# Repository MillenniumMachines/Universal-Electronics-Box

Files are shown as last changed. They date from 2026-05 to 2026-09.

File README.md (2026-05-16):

# Universal Electronics Box

Modular DIN-rail electronics enclosure for Millennium CNC builds—designed to pair with [Milo V2 / Miley V2](https://github.com/MillenniumMachines/Milo-V2.0).

**Repository:** [github.com/MillenniumMachines/Universal-Electronics-Box](https://github.com/MillenniumMachines/Universal-Electronics-Box)

This repository contains **STLs**, **panel DXFs**, **master CAD**, the **bill of materials** spreadsheet, **print list**, and the **wiring reference PDF**. Human-readable BOM, print settings, and part tables live on the [UEB section of the Millennium Machines documentation site](https://millenniummachines.github.io/docs/ueb/); see also the [main documentation hub](https://millenniummachines.github.io/docs/) for other Millennium projects.

## Documentation

| Topic | Location |
| --- | --- |
| All Millennium Machines guides | [Documentation hub](https://millenniummachines.github.io/docs/) |
| Overview, safety, repo layout | [UEB docs — Overview](https://millenniummachines.github.io/docs/ueb/) |
| Bill of materials and contactor options | [Sourcing guide](https://millenniummachines.github.io/docs/ueb/bom/sourcing_guide/) |
| Print profiles and printed parts | [Printing guide](https://millenniummachines.github.io/docs/ueb/printing/print_guide/) |
| Mains, E-stop, PSU, and signal wiring | [Millennium Universal CNC wiring .pdf](Millennium%20Universal%20CNC%20wiring%20.pdf) |
| Milo mechanical build, RRF, pre-flight | [MiloV2-Manual.pdf](https://github.com/MillenniumMachines/Milo-V2.0/blob/main/Manual/MiloV2-Manual.pdf) |

Source spreadsheets in this repo (also reflected on the docs site):

- `Electronics Cabinet BOM.xlsx`
- `Milennium Universal Electronics box Print List.xlsx`

## Repository layout

```
CAD/          Master assembly STEP
DXFs/         Top/bottom and side panel outlines
STLs/
  Panels/     Covers, clips, handles, keystone blanks
  Mounts/     DIN-rail mounts (Scylla, LRS-350 PSU)
  Cable channels/   Lids and trays for wire routing
              TPU-Foot-x4-A.stl (optional feet)
```

## Printing quick reference

Use **0.2 mm** layers and a **0.4 mm** nozzle unless you are experimenting. Profile codes in filenames match the print list:

| Code | Use |
| --- | --- |
| **S** | Structural — 45% infill, 6 walls |
| **SS** | Semi-structural — 25% infill, 4 walls |
| **A** | Aesthetic — 20% infill, 3 walls |

- **`[a]`** prefix — accent filament
- **`x#`** suffix — quantity required (e.g. `x4` → four copies)
- **`Voron-Inserts`** in the filename — print the variant that matches your heat-set inserts (Voron vs CNC-Kitchen)

See the [printing guide](https://millenniummachines.github.io/docs/ueb/printing/print_guide/) for the full part list.

## Wiring

The wiring PDF is titled **V2 / V1.6 wiring reference**. It covers mains inlet, breaker, contactor, 24 V distribution, E-stop, and machine interconnect—follow it together with your local electrical code.

> **Warning:** This enclosure operates at **mains voltage**. Use a suitable E-stop, correct wire gauges for your region, and qualified help if you are unsure. Do not energize the cabinet until wiring has been checked.

## Related projects

- [Milo-V2.0](https://github.com/MillenniumMachines/Milo-V2.0) — mechanical mill (electronics not included in that repo)
- [Millennium Machines documentation](https://millenniummachines.github.io/docs/) — published guides (UEB, Milo, and other projects)
- [millenniummachines.github.io](https://github.com/MillenniumMachines/millenniummachines.github.io) — documentation site source

## License

See repository license file when published. Until then, treat CAD and STLs as part of the Millennium Machines open hardware ecosystem and follow project guidance on Discord for use and redistribution.

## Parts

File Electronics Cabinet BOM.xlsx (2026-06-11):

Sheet: Electronics
Category | Component | Standard | QTY | Note | Note 2 | Recommended | Alternative
Filament | Primary Color ABS/ASA |  | 2
Filament | Primary Color TPU |  | 1 | (OPTIONAL for the case feet) | Amazon (https://www.amazon.co.uk/Filament-1-75mm-Eryone-Printing-Printer/dp/B07XNYTPN9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)
Printed parts | Printed parts |  | 1
Fasteners | M3x10mm SHCS | ISO 4762 / DIN 912 | 40 | (extra fatseners are included in this list) | ACCU (https://www.accu.co.uk/cap-head-screws/3819-SSCF-M3-10-A2)
Fasteners | M3x30mm SHCS | ISO 4762 / DIN 912 | 6 |  | ACCU (https://www.accu.co.uk/metric-cap-head-screws/2805-SSC-M3-30-A2)
Fasteners | M4x6mm BHCS | ISO 7380-0 | 4 |  | ACCU (https://www.accu.co.uk/socket-button-screws/8127-SSB-M4-6-A2)
Fasteners | M5x10mm BHCS | ISO 7380-1 | 28 |  | ACCU (https://www.accu.co.uk/socket-button-screws/8147-SSB-M5-10-A2)
Fasteners | M5x12mm BHCS | ISO 7380-1 | 10 |  | ACCU (https://www.accu.co.uk/socket-button-screws/8148-SSB-M5-12-A2)
Fasteners | M3 heated inserts |  | 14 | (Choose between voron style or cnc kitchen style inserts) | CNC KITCHEN (https://cnckitchen.store/products/heat-set-insert-m3-x-3-short-version-100-pieces) | Aliexpress (https://s.click.aliexpress.com/e/_ol2Yb5O)
Fasteners | M5 roll in T nut |  | 2 |  | Aliexpress (https://www.aliexpress.com/item/1005004082080953.html)
Fasteners | M3 roll in T nut |  | 20 |  | Aliexpress (https://www.aliexpress.com/item/1005004082080953.html)
Fasteners | M5 serrated washer |  | 2 | (This is for grounding the Frame of the control box and whatever Machine its attached to) | Amazon (https://www.amazon.co.uk/sourcing-map-Mechanical-Equipment-Fasteners/dp/B0D9VTPJ9F?s=diy)
Frame | 2020 V-slot extrusion 140mm |  | 4 | (Tap both ends of all extrusions) | Ooznest (https://ooznest.co.uk/product/v-slot-linear-rail-20x20mm-cut-to-size/)
Frame | 2020 V-slot extrusion 430mm |  | 4 |  | Ooznest (https://ooznest.co.uk/product/v-slot-linear-rail-20x20mm-cut-to-size/)
Frame | 2020 V-slot extrusion 410mm |  | 4 |  | Ooznest (https://ooznest.co.uk/product/v-slot-linear-rail-20x20mm-cut-to-size/)
Cables | 18AWG (min) Mains wiring (neutral, line, ground) |  |  | NOTE : WIRING LENGTHS WILL CHANGE DEPENDING ON YOUR NEEDS consult your local guidelines for regulation wiring sizes
Cables | 18AWG 4 Core for spindle Power
Cables | 20AWG wire for DC power distribution
Cables | 24AWG wire for signal cables
Cables | Nylon Cable Ties (less than 5mm wide) |  | 100 |  | Amazon (https://amzn.to/3NmmzLt)
Cables | Fork Spade Terminal |  |  |  | Amazon (https://amzn.to/37Ziyxk)
Cables | Ferrule CableTerminations |  |  | (size and use where appropriate) | Amazon (https://amzn.to/3wu2NYK)
Cables | JST Connector 3 Pin |  |  |  | Amazon (https://amzn.to/3G0HRvs)
Cables | Cable Gromets for ID 30mm |  | 3 |  | Amazon (https://www.amazon.co.uk/dp/B0CLXLZ8WJ?ref=ppx_yo2ov_dt_b_fed_asin_title&th=1)
Hardware | 35mm DIN Rail 410mm |  | 2 |  | RS components (https://uk.rs-online.com/web/p/din-rails/8990917)
Panels | 186x450mm 3mm ACM/Acrylic/Polycarbonate |  | 2
Panels | 430x450mm 3mm ACM/Acrylic/Polycarbonate |  | 2
Electronics | Fan | 24V 120mm | 1 |  | amazon (https://www.amazon.co.uk/dp/B087FG4QPF?ref_=ppx_hzsearch_conn_dt_b_fed_asin_title_1&th=1)
Electronics | Estop | 2 NC | 1 |  | RS components (https://uk.rs-online.com/web/p/emergency-stop-push-buttons/1682546?matchtype=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)
Electronics | Meanwell LRS-350 | 24-60V (recommended 48V) | 1 |  | Digikey (https://www.digikey.co.uk/en/products/detail/mean-well-usa-inc/LRS-350-24/7705034)
Electronics | Meanwell HDR-30 | 24V | 1 |  | amazon (https://www.amazon.co.uk/dp/B06XWVHW8V?ref_=ppx_hzsearch_conn_dt_b_fed_asin_title_1)
Electronics | KCD4 rocker switches | 220V or 110V rated switches | 1 | only 1 is required should you want, to add more for auxiliaries go ahead | amazon (https://www.amazon.co.uk/dp/B0B7RDZKQL?ref_=ppx_hzsearch_conn_dt_b_fed_asin_title_1)
Electronics | BTT Scylla |  | 1 |  | Scylla (https://www.desktopmachineshop.com/shop/btt-scylla-v1-180?page=3)
Electronics | USB/HDMI/RJ45 keystone jacks |  | 0 to 4 | Should you wish to install a Raspberry pi there are 4 available spots for keystone jacks these are optional. | HDMI (https://www.amazon.co.uk/dp/B0CN2BW2H1?ref_=ppx_hzsearch_conn_dt_b_fed_asin_title_1&th=1) | USB (https://www.amazon.co.uk/dp/B07Z9446ZR?ref_=ppx_hzsearch_conn_dt_b_fed_asin_title_3&th=1) | RJ45 (http://amazon.co.uk/dp/B01GFWSSYQ?ref_=ppx_hzsearch_conn_dt_b_fed_asin_title_2)
Electronics | Raspberry pi 4/5 8GB |  | 0 or 1 | Optional you can use your phone/PC/tablet instead (you will need to provide your own DIN mount for the pi) | amazon (https://www.amazon.co.uk/Raspberry-Pi-SC1112-5-8GB/dp/B0CK2FCG1K)
Electronics | DIN AC terminal Hot |  | 3 | Colors may be different depending on your region, please refer to your countries electrical code | RS components (https://uk.rs-online.com/web/p/din-rail-terminal-blocks/0815694)
Electronics | DIN AC terminal Neutral |  | 3 |  | RS components (https://uk.rs-online.com/web/p/din-rail-terminal-blocks/0501819?gb=s)
Electronics | DIN AC terminal Ground |  | 3 |  | RS components (https://uk.rs-online.com/web/p/din-rail-terminal-blocks/8725621)
Electronics | Power inlet | IEC20 | 1 | You can buy combined inlet EMI filters in 110V countries eliminating the need for both | amazon (https://www.amazon.co.uk/dp/B0C4F9RYS8?ref_=ppx_hzsearch_conn_dt_b_fed_asin_title_1)
220V 2.2KW Spindle
Electronics | DIN contactor | 24V DC coil voltage, 3 channel, 220V AC @ 16A | 1 |  | TME (https://www.tme.eu/gb/details/gmd-16m-24vdc-1b/contactors-main-modules/ls-electric/gmd-16m-24vdc-1b/)
Electronics | Mini circuit breaker | 13A 220V 2 Pole | 1 |  | amazon (https://www.amazon.co.uk/dp/B0018LB3UQ?ref_=ppx_hzsearch_conn_dt_b_fed_asin_title_2)
Electronics | AC EMI filter | 13A 220V | 1 | You may be able to get away if you want to save some money with no EMI filter especially in 220V countries. If you experience any issues due to EMI add one later | amazon (https://www.amazon.co.uk/sourcingmap®-CW4L2-10A-T-Noise-Suppressor-Filter/dp/B016EISSGE?s=industrial)
Electronics | Power Cable | IEC C19 to IEC 60309 | 1 |  | amazon (https://www.amazon.co.uk/dp/B07MPP8X9M?ref_=ppx_hzsearch_conn_dt_b_fed_asin_title_1)
Electronics | VFD | 220V 2.2KW | 1
Electronics | Spindle | 2 or 4 pole 400Hz 220V 2.2KW | 1
110V 2.2KW spindle |  |  |  | WARNING Most domestic power systems in 110V countries like the US can only "just" provide enough amperage for a 2.2Kw spindle we do not recommend using one without a dedicated circuit
Electronics | DIN contactor | 24V DC coil voltage, 3 channel, 110V AC @ 20A | 1 | Contactors rated for 220V will also work for 110V but not the other way around | automation direct (https://www.automationdirect.com/adc/shopping/catalog/motor_controls/iec_magnetic_contactors/iec_contactors/hmc-22b30-11-ds)
Electronics | DIN Mini circuit breaker | 20A 110V 2 pole | 1 |  | amazon (https://amzn.to/3FzbfNO)
Electronics | AC EMI filter | 20A 110V | 1 | You may be able to get away if you want to save some money with no EMI filter. If you experience any issues due to EMI add one later | amazon (https://amzn.to/4dK8yW9)
Electronics | Power Cable | IEC C19 to Nema 5-20P | 1 |  | amazon (https://amzn.to/43Qu2MN)
Electronics | VFD | 110V 2.2KW | 1
Electronics | Spindle | 2 or 4 pole 400Hz 110V 2.2KW | 1
220V 1.5KW spindle
Electronics | DIN contactor | 24V DC coil voltage, 3 channel, 220V AC @ 16A | 1 |  | TME (https://www.tme.eu/gb/details/gmd-16m-24vdc-1b/contactors-main-modules/ls-electric/gmd-16m-24vdc-1b/)
Electronics | Mini circuit breaker | 13A 220V 2 pole | 1 |  | amazon (https://www.amazon.co.uk/dp/B0018LB3UQ?ref_=ppx_hzsearch_conn_dt_b_fed_asin_title_2)
Electronics | AC EMI filter | 13A 220V | 1 | You may be able to get away if you want to save some money with no EMI filter especially in 220V countries. If you experience any issues due to EMI add one later | amazon (https://www.amazon.co.uk/sourcingmap®-CW4L2-10A-T-Noise-Suppressor-Filter/dp/B016EISSGE?s=industrial)
Electronics | Power Cable | IEC C19 to IEC 60309 | 1 |  | amazon (https://www.amazon.co.uk/dp/B07MPP8X9M?ref_=ppx_hzsearch_conn_dt_b_fed_asin_title_1)
Electronics | VFD | 220V 1.5KW | 1 |  | DMS (https://www.desktopmachineshop.com/shop/ldo-inverter-vfd-1-5kw-220v-shinlin-38)
Electronics | Spindle | 2 or 4 pole 400Hz 220V 1.5KW | 1 |  | DMS (https://www.desktopmachineshop.com/shop/ldo-spindle-motor-1-5kw-220v-37)
110V 1.5KW spindle
Electronics | DIN contactor | 24V DC coil voltage, 3 channel, 110V AC @ 16A | 1 | Contactors rated for 220V will also work for 110V but not the other way around | automation direct (https://www.automationdirect.com/adc/shopping/catalog/motor_controls/iec_magnetic_contactors/iec_contactors/hmc-18b30-11-ds)
Electronics | Mini circuit breaker | 15A 110V 2 pole | 1 |  | amazon (https://amzn.to/4mKpShW)
Electronics | AC EMI filter | 15A 110V | 1 | You may be able to get away if you want to save some money with no EMI filter. If you experience any issues due to EMI add one later | amazon (https://amzn.to/4dK8yW9)
Electronics | Power Cable | IEC C19 to Nema 5-15P | 1 |  | amazon (https://amzn.to/3Sx5fIl)
Electronics | VFD | 110V 1.5KW | 1 |  | West3D (https://west3d.com/products/inverter-for-cnc-machines-milo-by-millennium-machines?variant=45225259696340)
Electronics | Spindle | 2 or 4 pole 400Hz 110V 1.5KW | 1 |  | West3D (https://west3d.com/products/inverter-for-cnc-machines-milo-by-millennium-machines?variant=45225259696340)

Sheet: Contactor Candidates
Manufacturer | Model | Rated Current | Rated Voltage | Poles | Auxilary Contacts | DBL Checked for 24v DC Control | Source 1 | Price | Source 2 | Price2 | Notes
Baomain | BMHC7-16 | 16 | 400 | 3 | 1NC | yes | https://baomain.com/products/baomain-dc-ac-modular-contactor-hum-free-16a-4pole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 | $15.39
Schneider Electric | LC1D18BD | 18 | 440 | 3 | 1NC+1NO | yes | https://www.amazon.com/dp/B0751H9SVM | $64.00 | https://www.aliexpress.us/item/3256807845054295.html | $33.19
Siemens | 3RT20161BB41 | 20 | 220* | 3 | 1NO | yes | https://www.amazon.com/Siemens-3RT20161BB41-Contactor-3-Pole-TERMINAL/dp/B003U6615Y/ | $38.60 | https://www.aliexpress.us/item/3256803379863717.html | $44.50 | Higher voltage rating, but amps derate at higher voltages. 20A for both 110 and 220V
Schneider Electric | DPE18BL | 40 | 220 | 3 | 1NO | yes | https://www.amazon.com/Schneider-Electric-DPE18BL-Contactor-Terminals/dp/B09B2SP56H/ | $39.98
Hofwge | HCH8s-63 | 25 | 220 | 4 |  | AC & DC | https://www.aliexpress.us/item/3256804432680878.html | $21.50
CHNT | NC1-1801Z | 18 | 380 | 3 | 1NC | yes | https://www.aliexpress.us/item/3256804690998153.html | $32.00 | https://www.aliexpress.us/item/2255800339794785.html | $18.83 | Source 2 Sale: $16.95
CHNT | NC1-1810Z | 18 | 380 | 3 | 1NO | yes |  |  | https://www.aliexpress.us/item/2255800339794785.html | $18.83 | Source 2 Sale: $16.95
CHNT | NC1-2501Z | 25 | 380 | 3 | 1NC | yes | https://www.aliexpress.us/item/3256804690998153.html | $40.00 | https://www.aliexpress.us/item/2255800339809617.html | $24.67 | Source 2 Sale: $22.20
CHNT | NC1-2510Z | 25 | 380 | 3 | 1NO | yes | https://www.aliexpress.us/item/3256804690998153.html | $40.00 | https://www.aliexpress.us/item/2255800339809617.html | $24.67 | Source 2 Sale: $22.21
Altech Corporation | GMD-16M-10-DC24V | 20 | 440 | 3 | 1NC | yes | https://www.tme.eu/gb/details/gmd-16m-24vdc-1b/contactors-main-modules/ls-electric/gmd-16m-24vdc-1b/ | $18.75 | https://us.misumi-ec.com/vona2/detail/110400268240/?HissuCode=GMD-16M-DC24V | $36.32 | Source 1: High shipping cost to US; Source 2 Sale: $14.49

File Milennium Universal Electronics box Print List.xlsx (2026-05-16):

Print Setting Name | Wall Count | Top/Bottom layers | Nozzle Size | Layer Height | Infill % | Infill Type
A (aesthetic) | 3 | 5 | 0.4mm | 0.2mm | 20 | Gyroid/Cubic
SS (semi structural) | 4 | 5 | 0.4mm | 0.2mm | 25 | Gyroid/Cubic
S (structural) | 6 | 6 | 0.4mm | 0.2mm | 45 | Gyroid/Cubic
Part Category | Part Name | Print Setting | Material | Quantity | Accent color Y/N | Note
Panels | [a]-Keystone-Blank-Insert-x4-A | A | ABS | 4 | Y | This is a VORON DESIGN part Go check them out (https://vorondesign.com/)
Panels | Extrusion-Handle-x2-A | A | ABS | 2 | N
Panels | Front-Estop-cover-34mm-x1-SS | SS | ABS | 1 | N
Panels | Front-Inlet-Cover-x1-A | A | ABS | 1 | N
Panels | Front-Mid-Cover-x1-A | A | ABS | 1 | N
Panels | Panel-Clip-F-x2-A | A | ABS | 2 | N
Panels | Rear-Inlet-Cover-Voron-Inserts-x1-A | A | ABS | 1 | N
Panels | Rear-Inlet-Cover-x1-A | A | ABS | 1 | N
Panels | Rear-lower-cover-x1-A | A | ABS | 1 | N
Panels | Rear-Mid-Cover-x1-A | A | ABS | 1 | N
Mounts | Din-Rail-Enclosure-Mount-x4-A | A | ABS | 4 | N
Mounts | LRS-350-DIN-Mount-x1-or-2-SS | SS | ABS | 1 or 2 | N | If your VFD isn't too big i'd recommend printing 2
Mounts | Scylla-Din-Adapter-Left-x1-SS | SS | ABS | 1 | N
Mounts | Scylla-Din-Adapter-Left-Voron-Inserts-x1-SS | SS | ABS | 1 | N
Mounts | Scylla-Din-Adapter-Right-x1-SS | SS | ABS | 1 | N
Mounts | Scylla-Din-Adapter-Right-Voron-Inserts-x1-SS | SS | ABS | 1 | N
Mounts | Scylla-Din-Mount-x2-SS | SS | ABS | 2 | N
Cable Channels | 145mm-Lid-x4-A | A | ABS | 4 | N | All of the cable ducts were made using THIS tool then modified further check it out (https://www.printables.com/model/516164-cable-raceway)
Cable Channels | 145mm-Tray-x4-A | A | ABS | 4 | N
Cable Channels | 165mm-Lid-x6-A | A | ABS | 6 | N
Cable Channels | 165mm-Tray-x6-A | A | ABS | 6 | N
Cable Channels | Corner-Lid-x4-A | A | ABS | 4 | N
Cable Channels | Corner-Tray-x4-A | A | ABS | 4 | N
Cable Channels | T-Junction-Lid-x2-A | A | ABS | 2 | N
Cable Channels | T-Junction-Tray-x2-A | A | ABS | 2 | N
Feet | TPU-Foot-x4-A | A | TPU | 4 | N

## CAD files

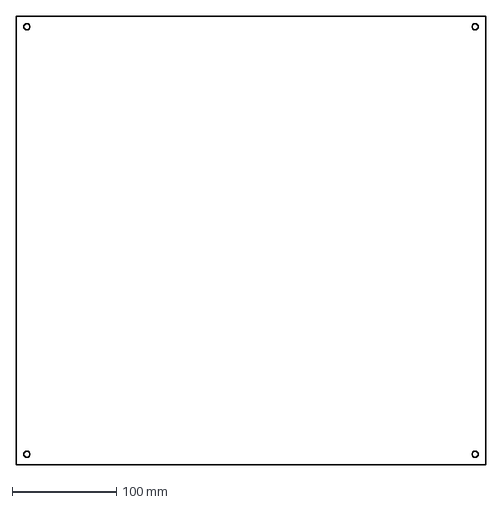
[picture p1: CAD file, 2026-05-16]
DXFs/Side-Panels-x2.dxf
450.0 x 430.0 mm

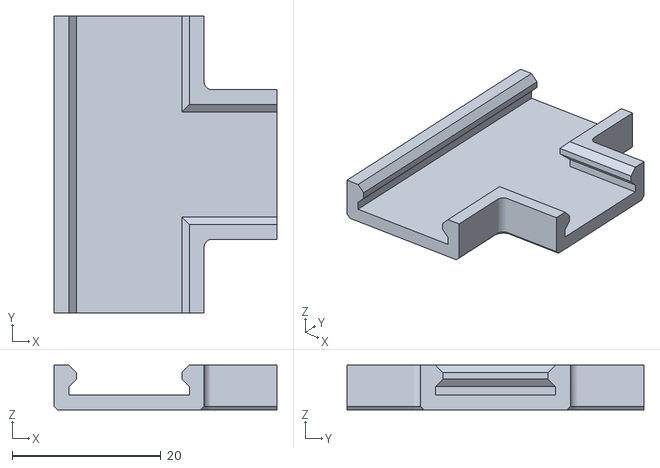
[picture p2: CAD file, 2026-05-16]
STLs/Cable channels/T-Junction-Lid-x2-A.stl
30.0 x 40.0 x 6.06

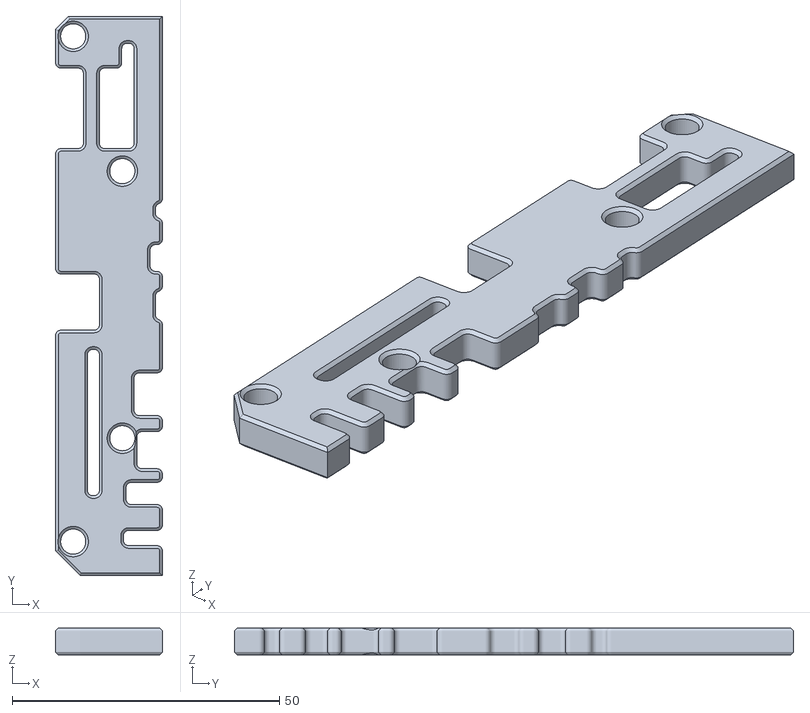
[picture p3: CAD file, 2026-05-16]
STLs/Mounts/Scylla-Din-Adapter-Left-Voron-Inserts-x1-SS.stl
20.0 x 104.6 x 5.00

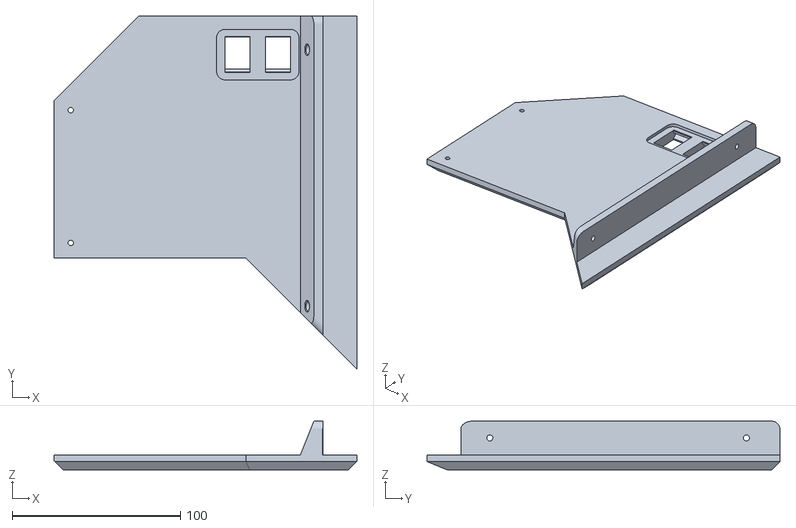
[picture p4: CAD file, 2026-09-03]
STLs/Panels/Front-Mid-Cover-x1-A.stl
180.0 x 209.9 x 29.0

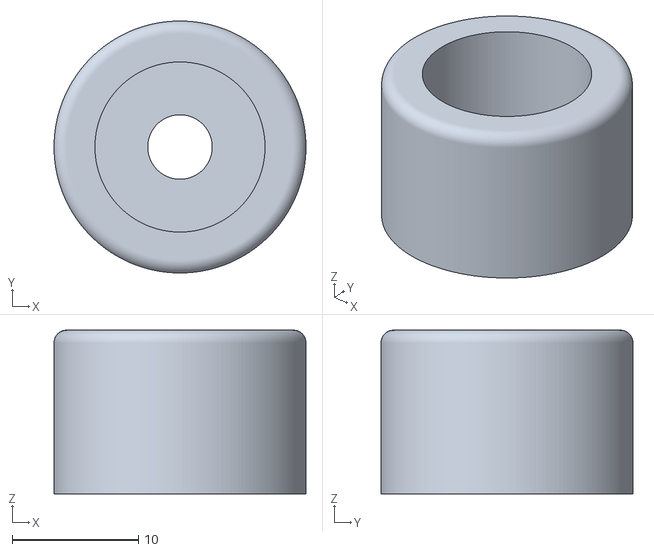
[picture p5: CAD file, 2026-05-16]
STLs/TPU-Foot-x4-A.stl
20.0 x 20.0 x 13.0

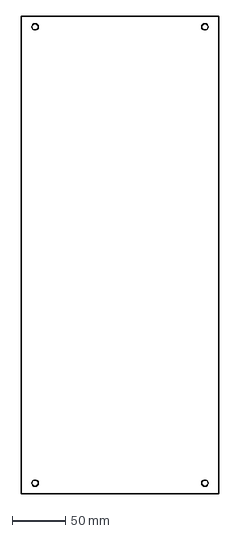
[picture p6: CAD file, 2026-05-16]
DXFs/Top-Bottom-Panel-x2.dxf
186.0 x 450.0 mm

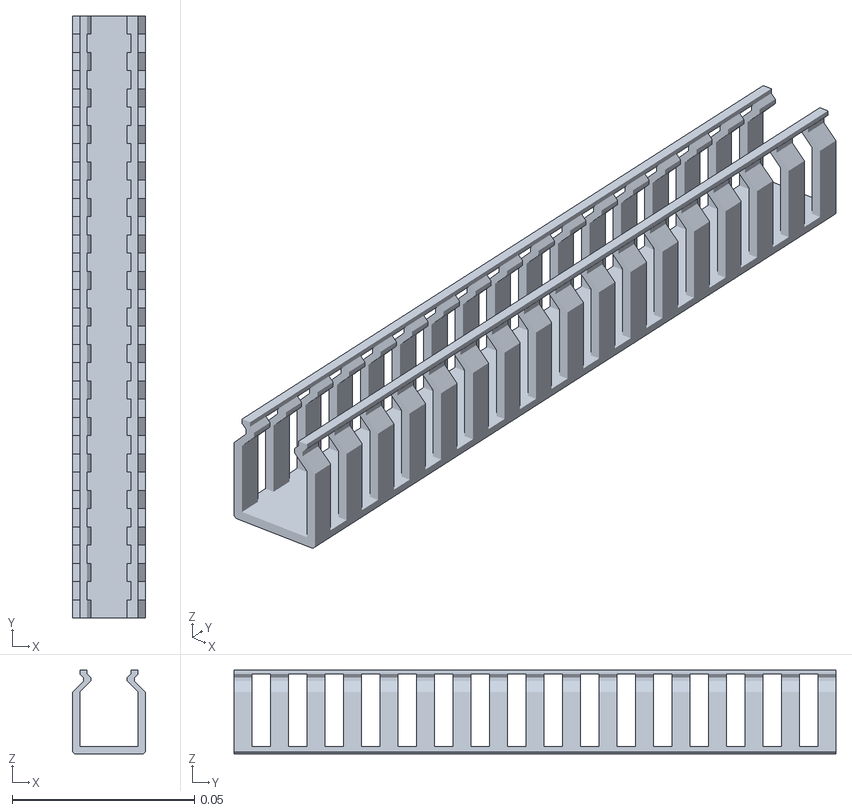
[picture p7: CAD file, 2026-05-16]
STLs/Cable channels/165mm-Tray-x6-A.stl
0.02 x 0.165 x 0.0229

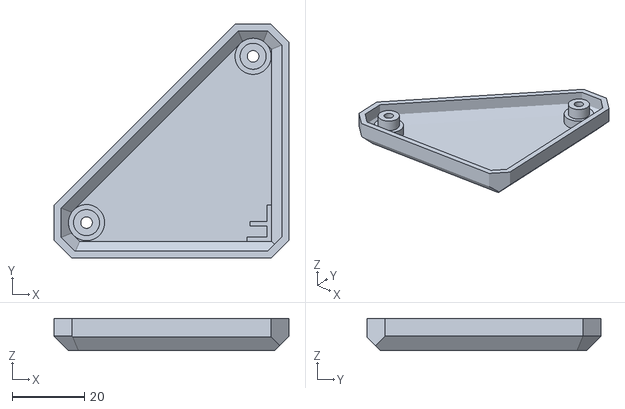
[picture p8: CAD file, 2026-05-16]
STLs/Panels/Panel-Clip-F-x2-A.stl
65.0 x 64.9 x 8.96

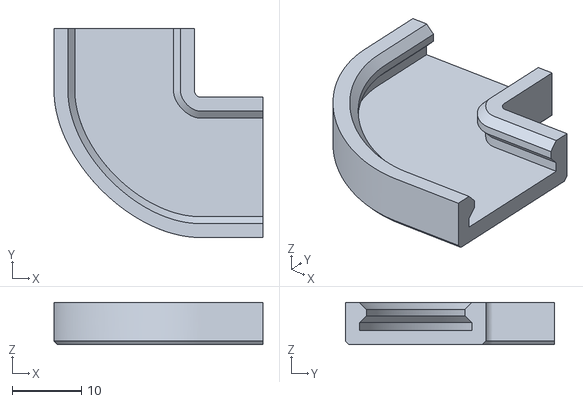
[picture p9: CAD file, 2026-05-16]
STLs/Cable channels/Corner-Lid-x4-A.stl
30.1 x 30.1 x 6.06

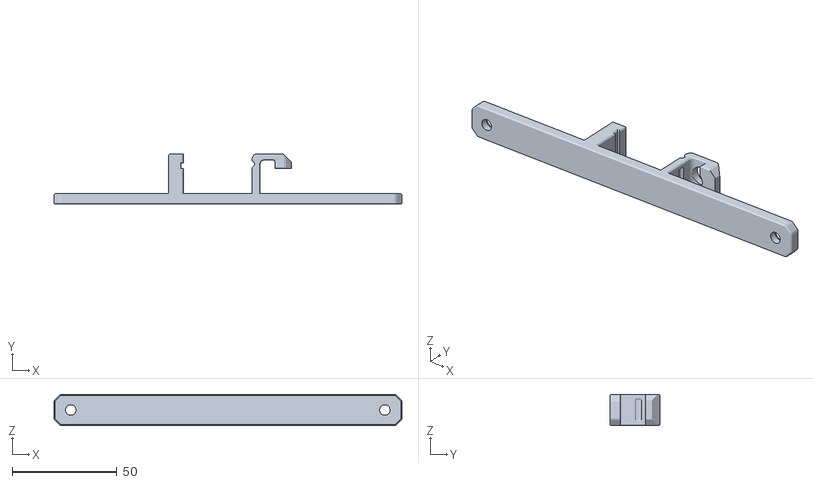
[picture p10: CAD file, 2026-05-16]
STLs/Mounts/LRS-350-DIN-Mount-x1-or-2-SS.stl
166.2 x 24.0 x 15.0

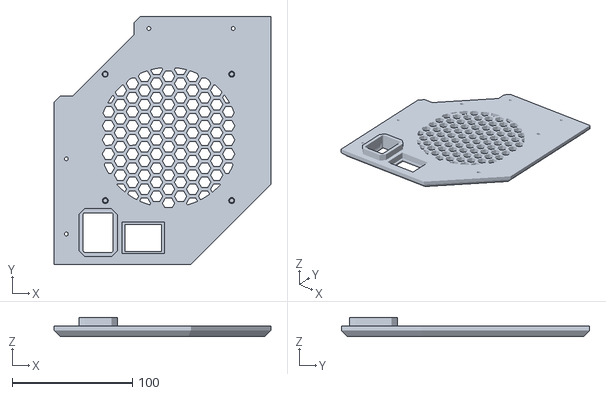
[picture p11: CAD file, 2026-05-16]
STLs/Panels/Rear-Inlet-Cover-x1-A.stl
180.0 x 206.0 x 16.0

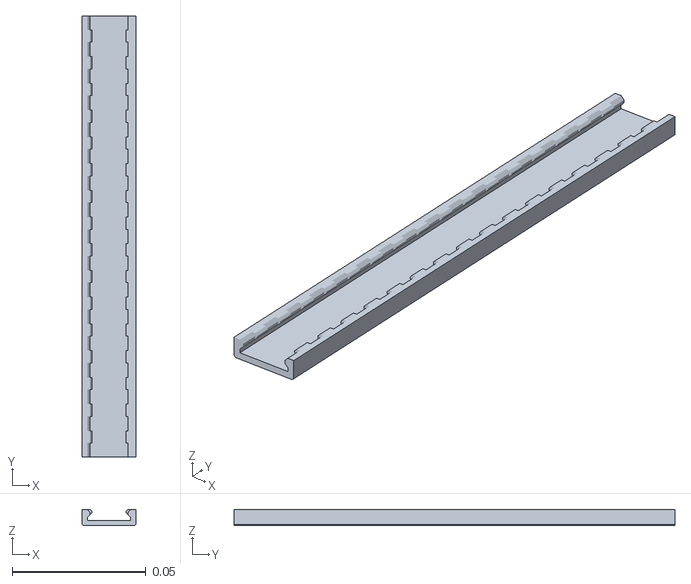
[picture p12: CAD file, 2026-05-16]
STLs/Cable channels/165mm-Lid-x6-A.stl
0.0202 x 0.165 x 0.00606

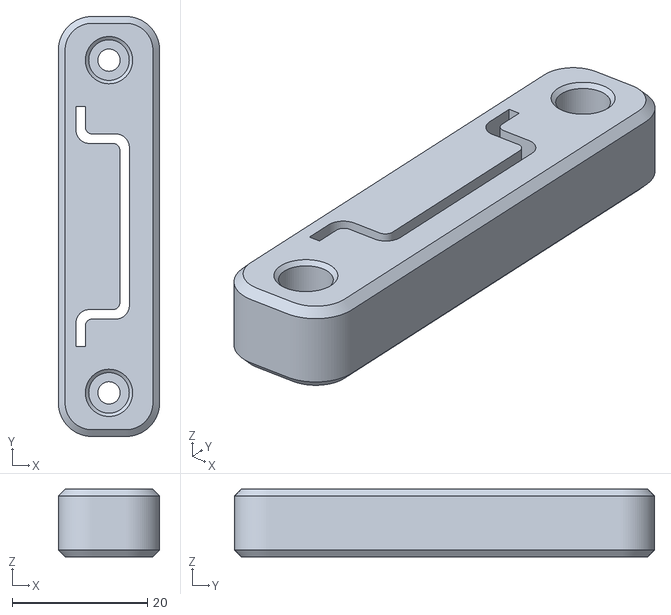
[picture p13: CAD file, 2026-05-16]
STLs/Mounts/Din-Rail-Enclosure-Mount-x4-A.stl
15.0 x 62.2 x 10.0

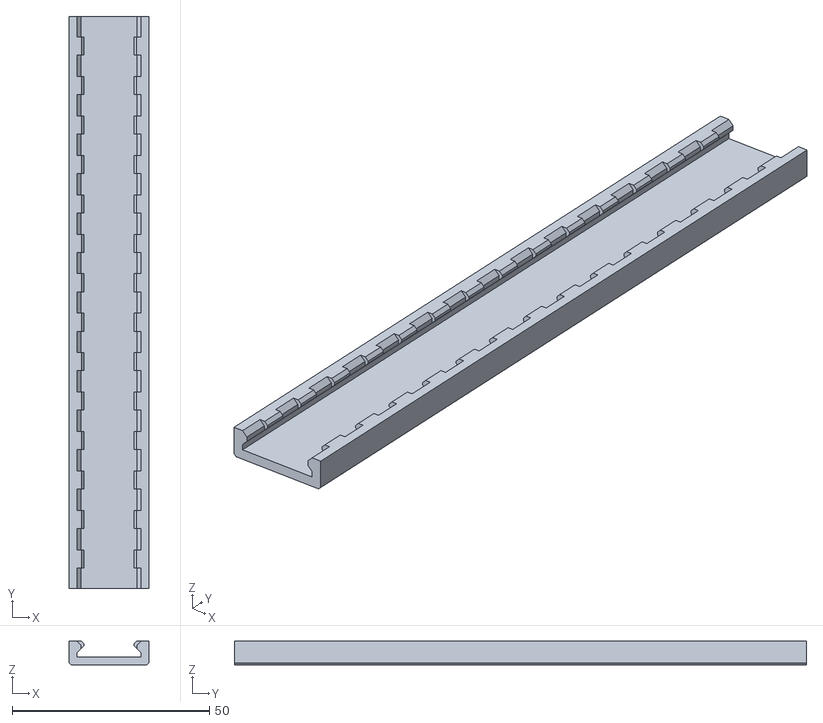
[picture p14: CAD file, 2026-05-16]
STLs/Cable channels/145mm-Lid-x4-A.stl
20.2 x 145.0 x 6.06

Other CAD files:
STLs/Mounts/Scylla-Din-Adapter-Left-x1-SS.stl
STLs/Panels/Rear-Inlet-Cover-Voron-Inserts-x1-A.stl
STLs/Mounts/Scylla-Din-Adapter-Right-Voron-Inserts-x1-SS.stl
STLs/Panels/Front-Inlet-Cover-x1-A.stl
STLs/Cable channels/145mm-Tray-x4-A.stl
STLs/Cable channels/Corner-Tray-x4-A.stl
STLs/Cable channels/T-Junction-Tray-x2-A.stl
STLs/Mounts/Scylla-Din-Adapter-Right-x1-SS.stl
STLs/Mounts/Scylla-Din-Mount-x2-SS.stl
STLs/Panels/Extrusion-Handle-x2-A.stl
STLs/Panels/Front-Estop-cover-34mm-x1-SS.stl
STLs/Panels/Rear-Mid-Cover-x1-A.stl
STLs/Panels/Rear-lower-cover-x1-A.stl
STLs/Panels/[a]-Keystone-Blank-Insert-x4-A.stl

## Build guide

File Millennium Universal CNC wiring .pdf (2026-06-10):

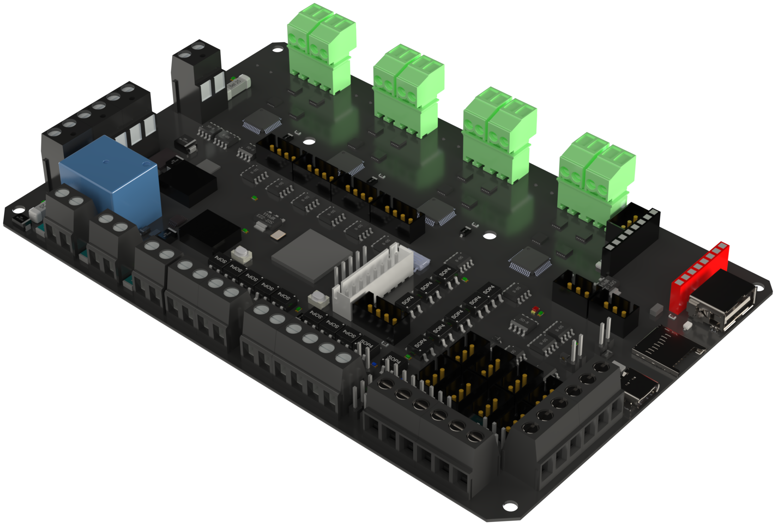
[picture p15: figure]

# V2 / V1.6 WIRING REFERENCE

www.millennium-machines.com/

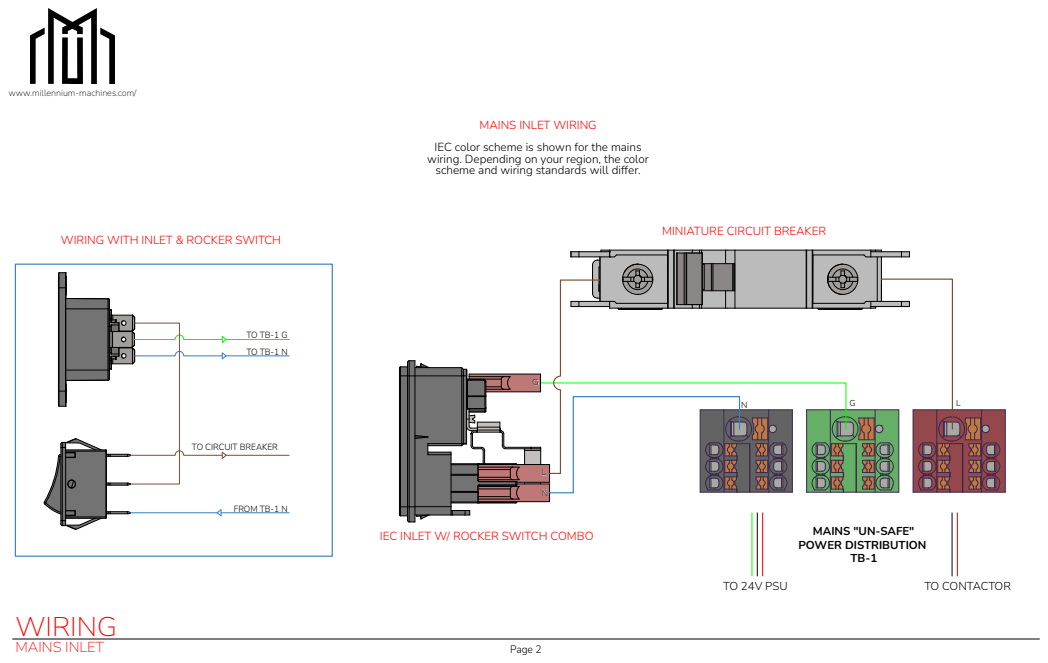
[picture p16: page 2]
MAINS INLET; Page 2; WIRING; TO 24V PSU; TO CONTACTOR; FROM TB-1 N

www.millennium-machines.com/

MAINS INLET WIRING

IEC color scheme is shown for the mains
wiring. Depending on your region, the color
scheme and wiring standards will differ.

MINIATURE CIRCUIT BREAKER

WIRING WITH INLET & ROCKER SWITCH

TO CIRCUIT BREAKER

MAINS "UN-SAFE"
POWER DISTRIBUTION

IEC INLET W/ ROCKER SWITCH COMBO

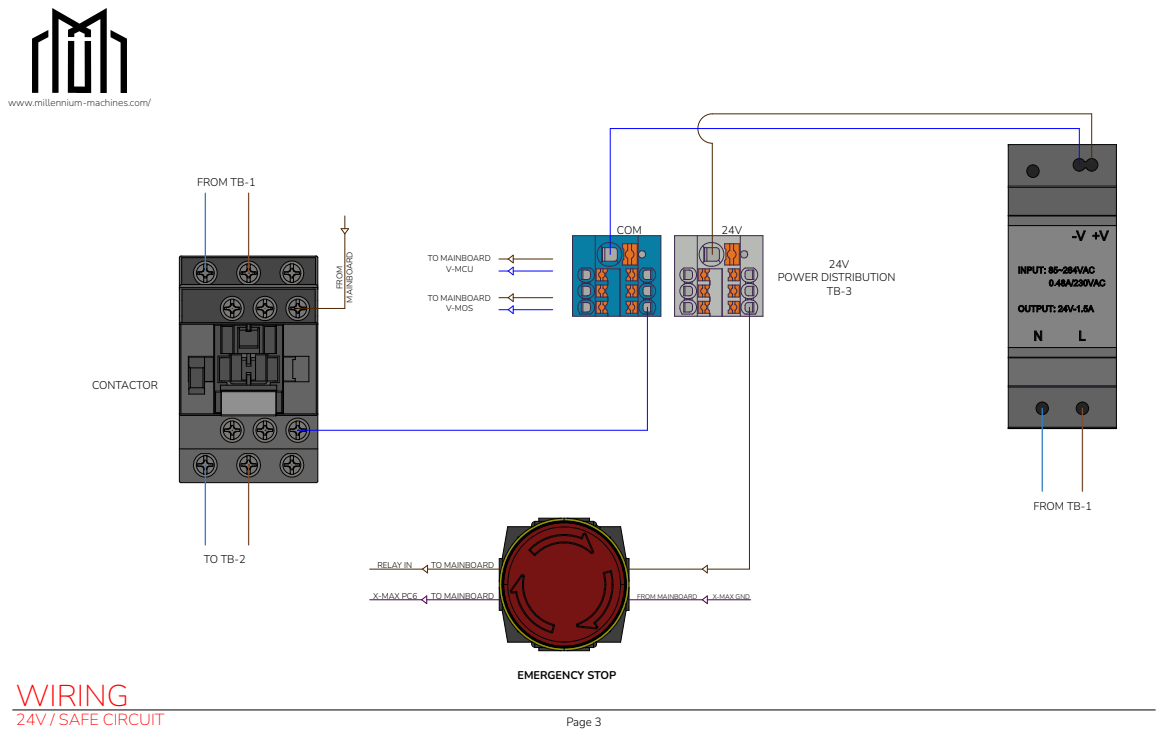
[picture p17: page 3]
24V / SAFE CIRCUIT; Page 3; WIRING; FROM TB-1; 24V POWER DISTRIBUTION TB-3; COM; FROM; MAINBOARD; TO MAINBOARD; FROM MAINBOARD; X-MAX PC6; X-MAX GND; RELAY IN; TO MAINBOARD V-MCU; TO MAINBOARD V-MOS; CONTACTOR; EMERGENCY STOP

www.millennium-machines.com/

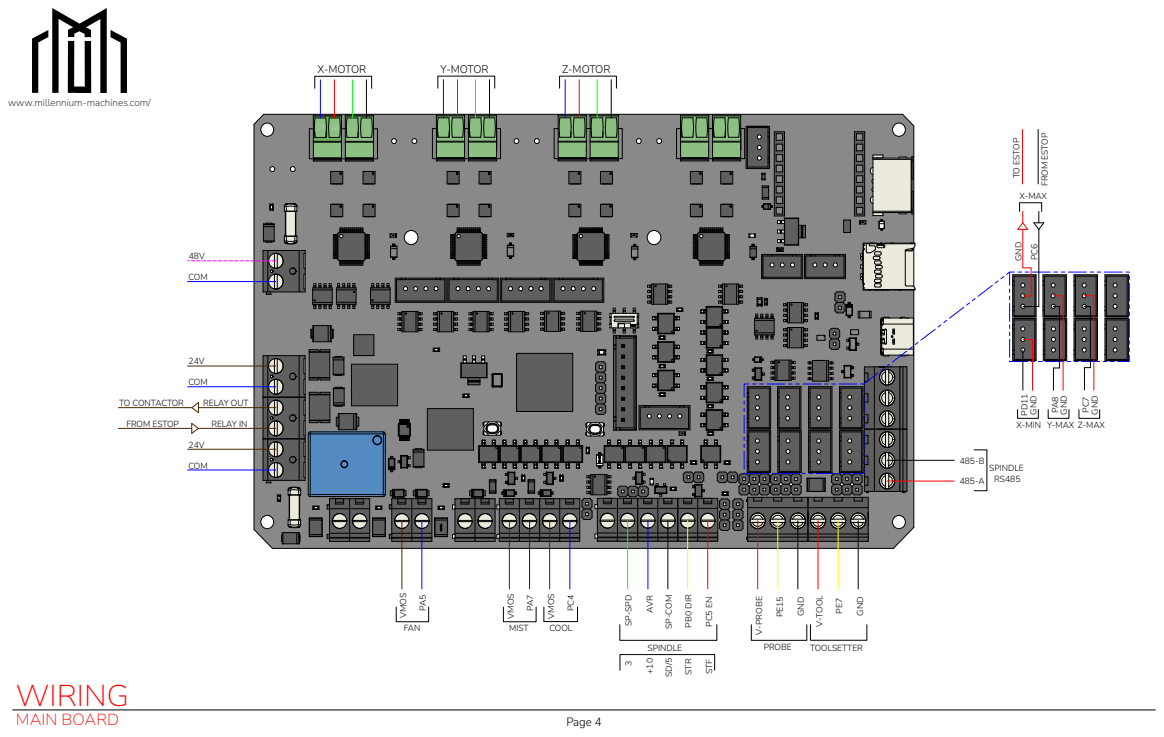
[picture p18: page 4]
MAIN BOARD; Page 4; WIRING; COM; AVR; SP-COM; PB0 DIR; SPINDLE; V-PROBE; GND; V-TOOL; PROBE; TOOLSETTER; X-MOTOR; Y-MOTOR; Z-MOTOR; SPINDLE RS485; VMOS; MIST; COOL; PD11 GND; SP-SPD; STR; STF; FROM ESTOP; TO CONTACTOR; TO ESTOP; RELAY OUT; RELAY IN; FAN

www.millennium-machines.com/

FROM ESTOP
X-MAX GND PC⁶

X-MIN Y-MAX Z-MAX

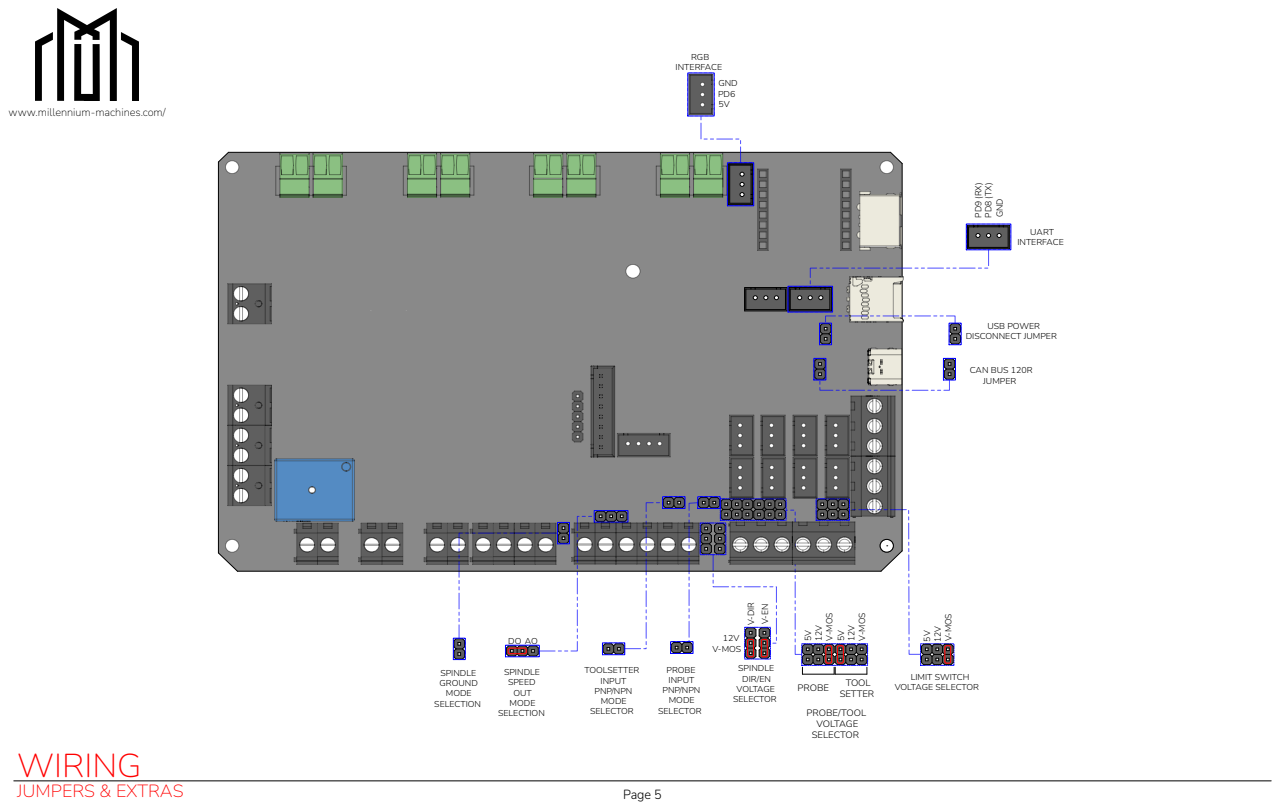
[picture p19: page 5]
JUMPERS & EXTRAS; Page 5; WIRING; V-MOS; PROBE/TOOL VOLTAGE SELECTOR; PROBE; TOOL; SETTER; SPINDLE SPEED OUT MODE SELECTION; SPINDLE GROUND MODE SELECTION; SPINDLE DIR/EN VOLTAGE; 12V V-MOS; PROBE INPUT PNP/NPN MODE SELECTOR; TOOLSETTER INPUT PNP/NPN MODE SELECTOR; LIMIT SWITCH VOLTAGE SELECTOR; RGB INTERFACE GND PD6 5V; CAN BUS 120R JUMPER; USB POWER; UART INTERFACE

www.millennium-machines.com/

DISCONNECT JUMPER PD⁹ ⁽RX⁾ PD⁸ ⁽TX⁾ GND

SELECTOR V⁻DIR V⁻EN

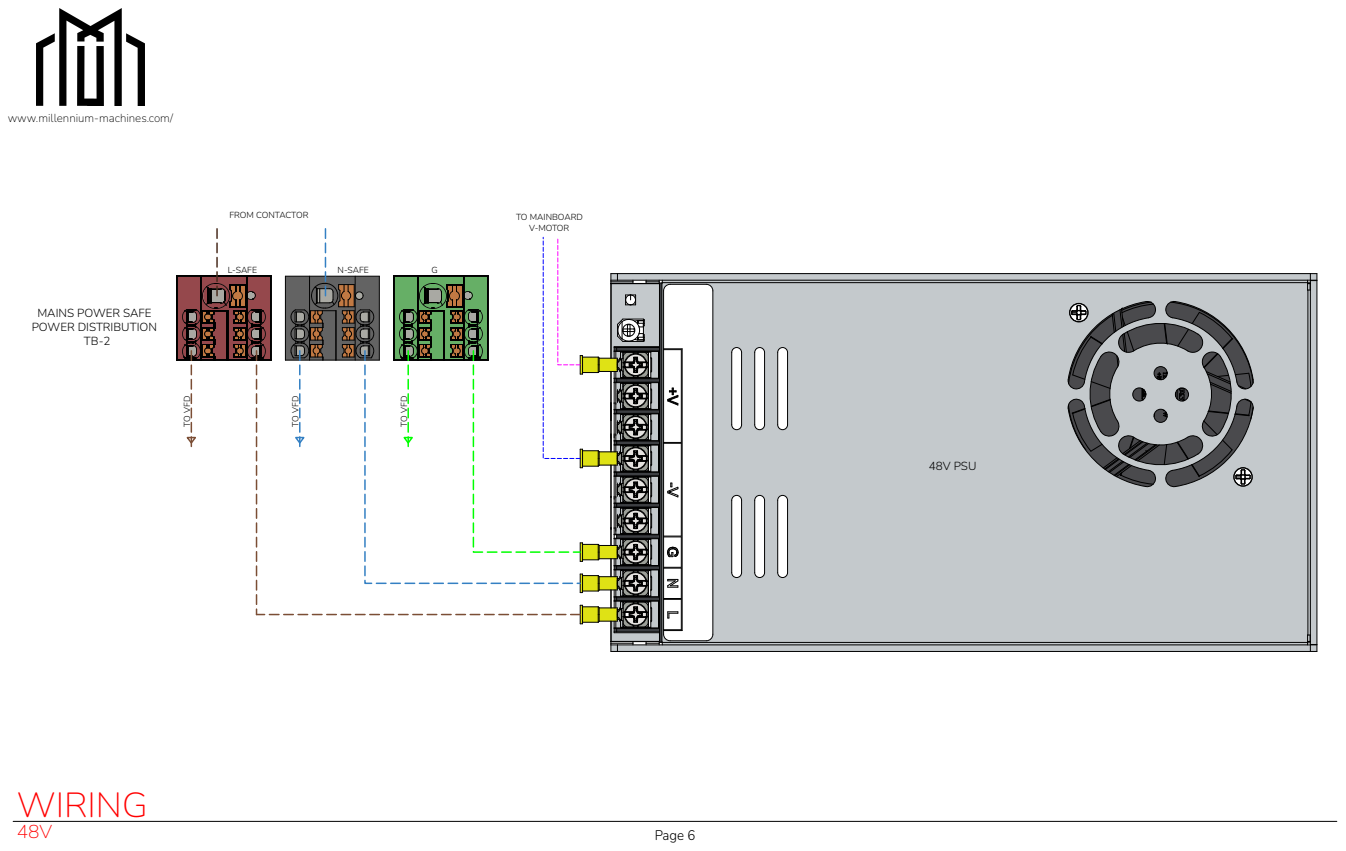
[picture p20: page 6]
Page 6; WIRING; L-SAFE; N-SAFE; FROM CONTACTOR; TO VFD; TO MAINBOARD V-MOTOR; 48V PSU

www.millennium-machines.com/

MAINS POWER SAFE
POWER DISTRIBUTION

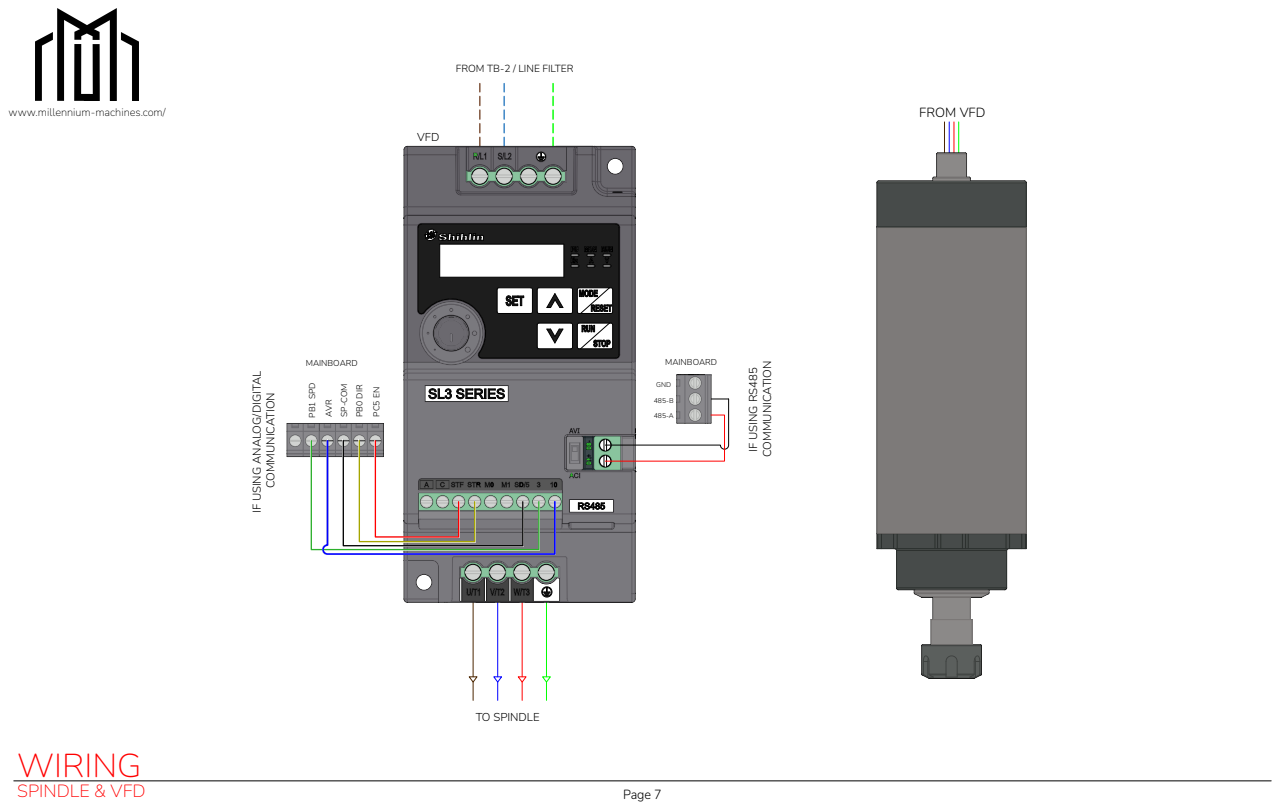
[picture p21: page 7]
SPINDLE & VFD; Page 7; WIRING; IF USING RS485; COMMUNICATION; VFD; MAINBOARD; TO SPINDLE; GND; PB1 SPD; AVR; SP-COM; PB0 DIR; FROM VFD

FROM TB-2 / LINE FILTER

www.millennium-machines.com/

IF USING ANALOG/DIGITAL

X-MOTOR | Y-MOTOR | Z-MOTOR

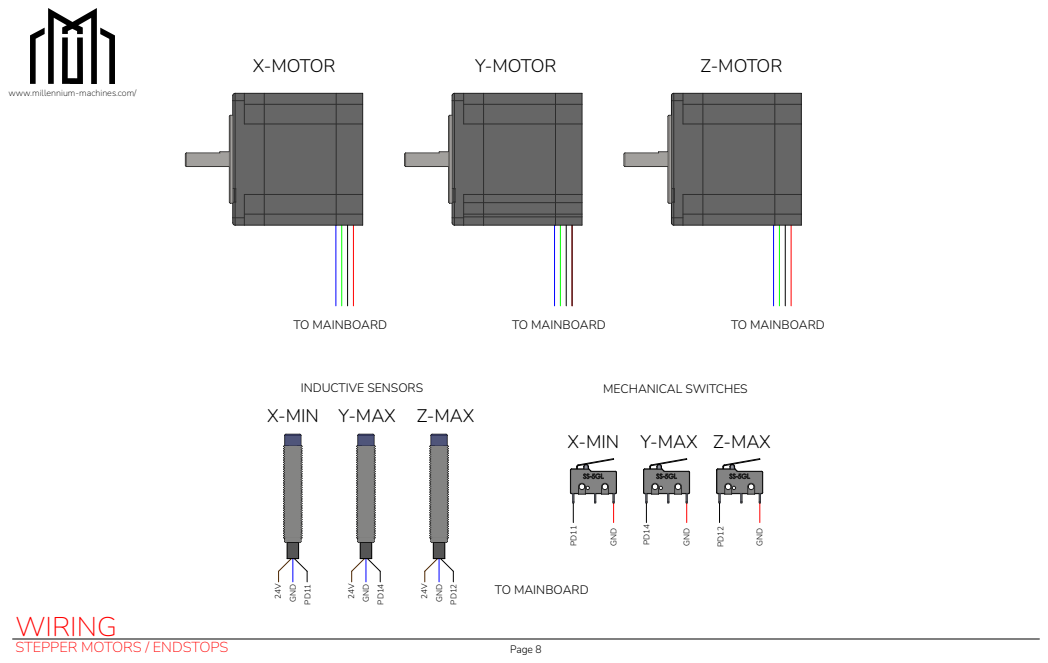
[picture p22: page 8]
STEPPER MOTORS / ENDSTOPS; Page 8; WIRING; INDUCTIVE SENSORS; MECHANICAL SWITCHES; TO MAINBOARDPD¹¹; GND; TO MAINBOARD

www.millennium-machines.com/

X-MIN Y-MAX Z-MAX GND PD¹² ²⁴V GND PD¹⁴ ²⁴V GND PD¹¹ ²⁴V

X-MIN Y-MAX Z-MAX

## PROBE

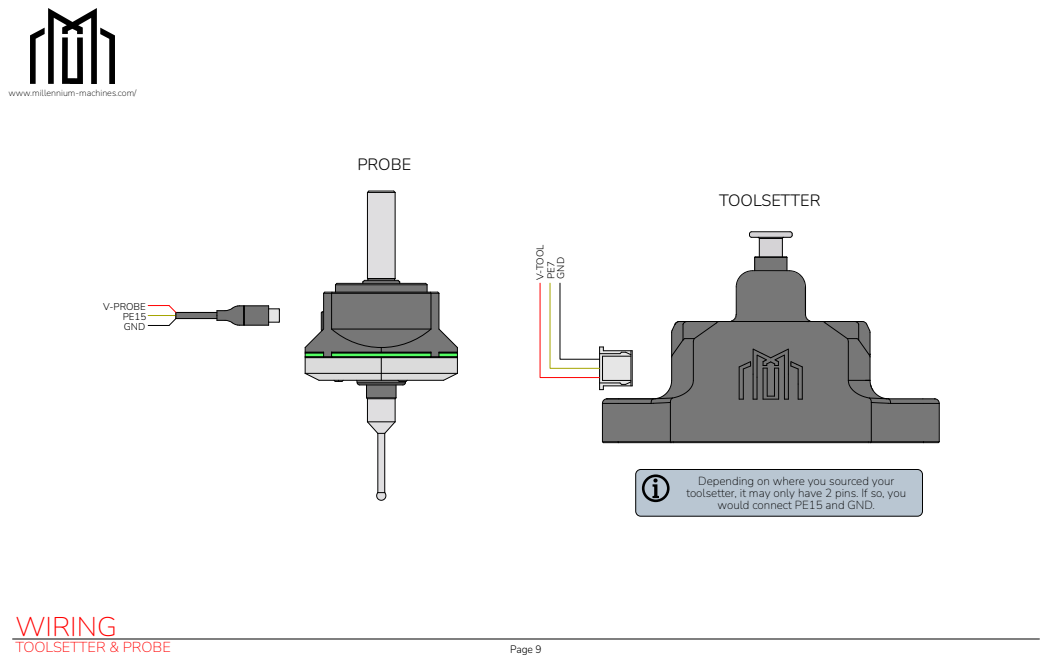
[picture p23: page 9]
TOOLSETTER & PROBE; Page 9; WIRING; V-TOOL; GND; V-PROBE PE15 GND; TOOLSETTER

www.millennium-machines.com/

Depending on where you sourced your
toolsetter, it may only have 2 pins. If so, you
would connect PE15 and GND.

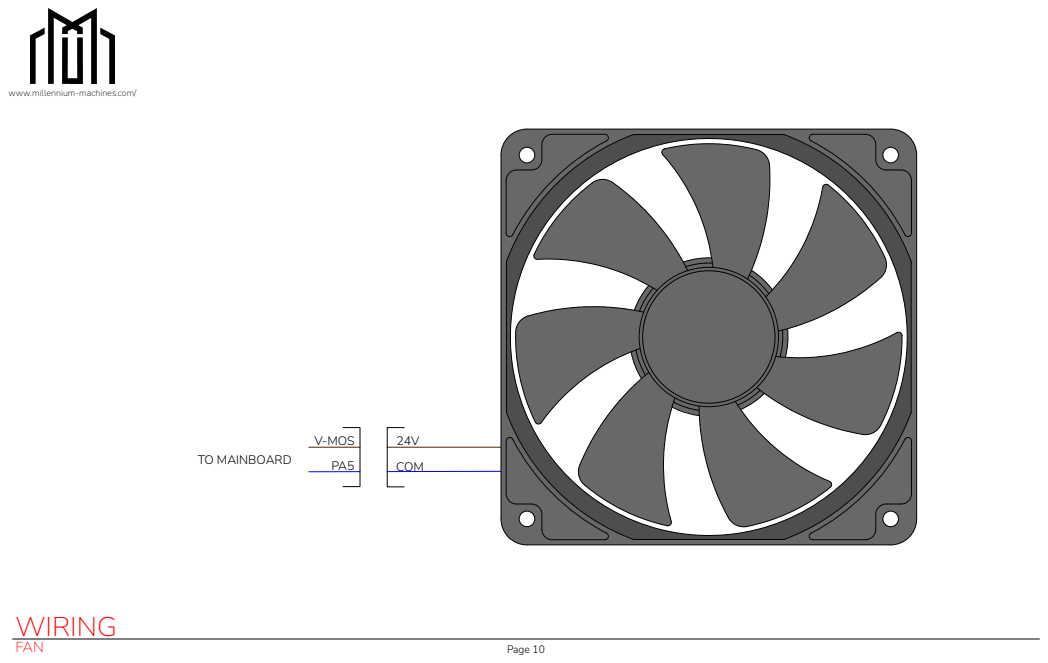
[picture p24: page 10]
FAN; Page 10; WIRING; COM; V-MOS PA5 TO MAINBOARD

www.millennium-machines.com/

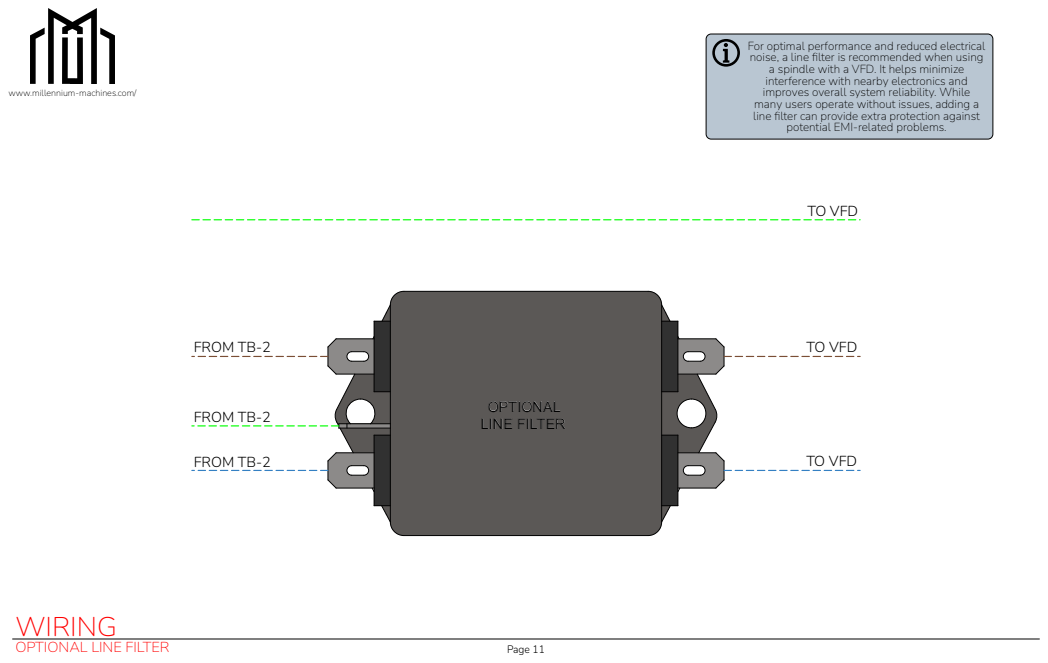
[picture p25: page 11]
OPTIONAL LINE FILTER; Page 11; WIRING; FROM TB-2; TO VFD

For optimal performance and reduced electrical
noise, a line filter is recommended when using
a spindle with a VFD. It helps minimize
interference with nearby electronics and
improves overall system reliability. While
many users operate without issues, adding a
line filter can provide extra protection against
potential EMI-related problems.

www.millennium-machines.com/

# CHANGE LOG

www.millennium-machines.com/

### Revision 06.09.26

- Changed E-Stop circuit to X-MAX GND instead of 24V.

### Revision 1.18.26 - Changed Drop Nut dimensions to center dims - Fixed Typo on Page 9 (Assembly → Assemble) - Added Keystone Insert info - Moved E-stop signals to Endstop - Imported the right version wiring diagram

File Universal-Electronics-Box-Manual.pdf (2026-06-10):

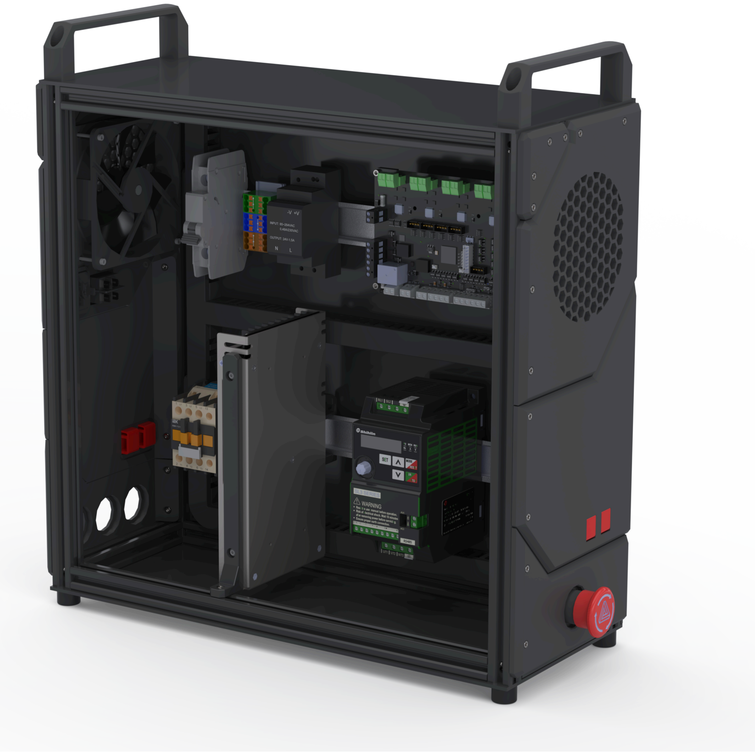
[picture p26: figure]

Version 01.18.2026 | Page 1

# UNIVERSAL ELECTRONICS BOX

www.millennium-machines.com/

# INTRODUCTION

www.millennium-machines.com/

The components and instructions in this manual can cause serious injury, fire, or damage to equipment if handled improperly. Power supplies, motor drivers, wiring, and control boards may carry hazardous voltages and currents even when the machine appears to be powered off. Always disconnect mains power before installing, modifying, or servicing any electrical components. Use properly rated wires, connectors, fuses, and grounding methods, and never bypass safety features or protective devices. Incorrect wiring, loose connections, or inadequate insulation can lead to electric shock, overheating, or fire. If there is anything, and we mean anything that you are curious or unsure about, you are more than welcome to ask us on our discord server.

The Universal Electronics Box (UBE) is our effort to standardize on a set of higher-performance, more reliable, and safer electronic components across all of our machines. The wiring diagram shown on page 22 represents our standard electrical layout and should be followed for all builds, even if you are installing the electronics in a Casa or another enclosure. Standardizing the wiring helps reduce errors, improves safety, and makes troubleshooting and future upgrades easier.

# TABLE OF CONTENTS

www.millennium-machines.com/

# QTY 2

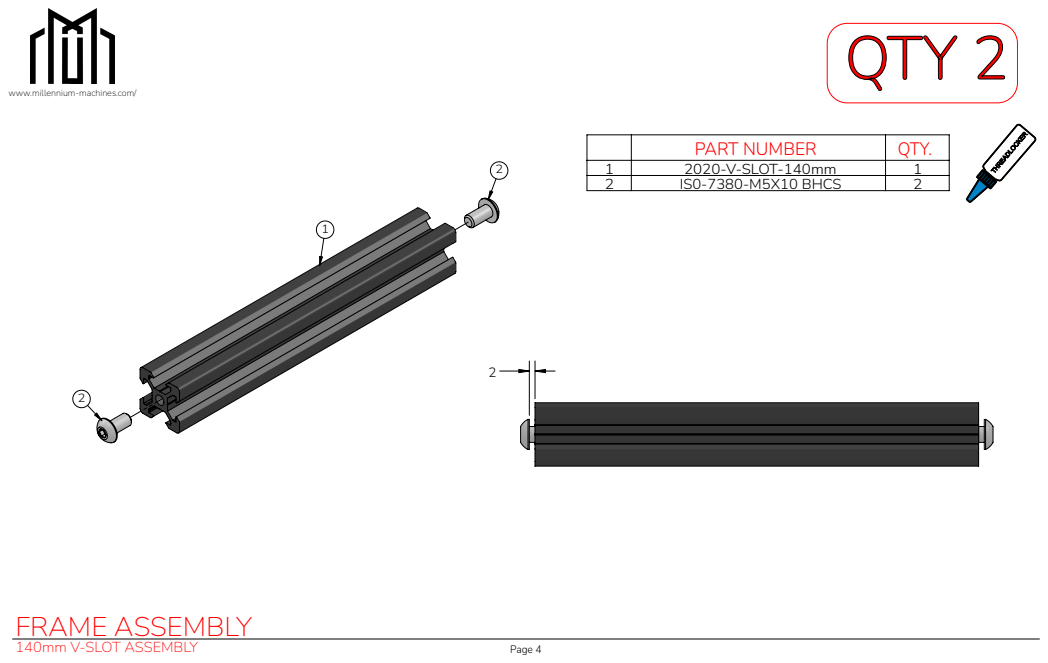
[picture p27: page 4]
140mm V-SLOT ASSEMBLY; Page 4; FRAME ASSEMBLY; THREADLOCKER

www.millennium-machines.com/

PART NUMBER | QTY.

1 | 2020-V-SLOT-140mm | 1
2 | IS0-7380-M5X10 BHCS | 2

# QTY 2

www.millennium-machines.com/

PART NUMBER | QTY.

1 | 2020-V-SLOT-430mm | 2
2 | 2020-V-SLOT-140mm-ASSEMBLY | 2

# QTY 2

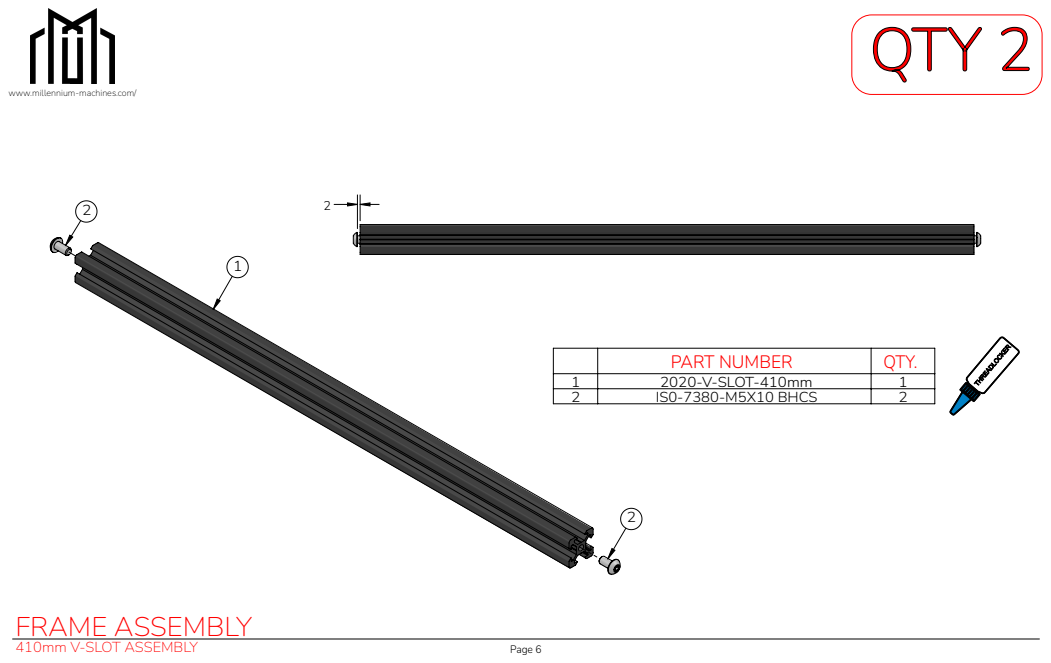
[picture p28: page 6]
410mm V-SLOT ASSEMBLY; Page 6; FRAME ASSEMBLY; THREADLOCKER

www.millennium-machines.com/

PART NUMBER | QTY.

1 | 2020-V-SLOT-410mm | 1
2 | IS0-7380-M5X10 BHCS | 2

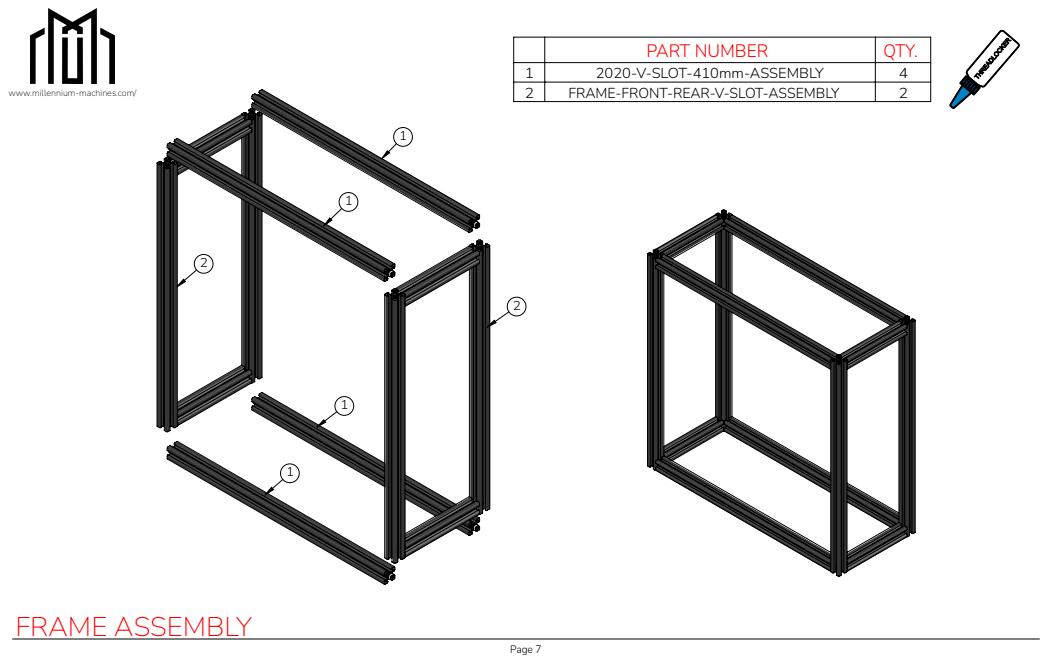
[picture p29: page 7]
FRAME ASSEMBLY; THREADLOCKER

PART NUMBER | QTY.

1 | 2020-V-SLOT-410mm-ASSEMBLY | 4
2 | FRAME-FRONT-REAR-V-SLOT-ASSEMBLY | 2

www.millennium-machines.com/

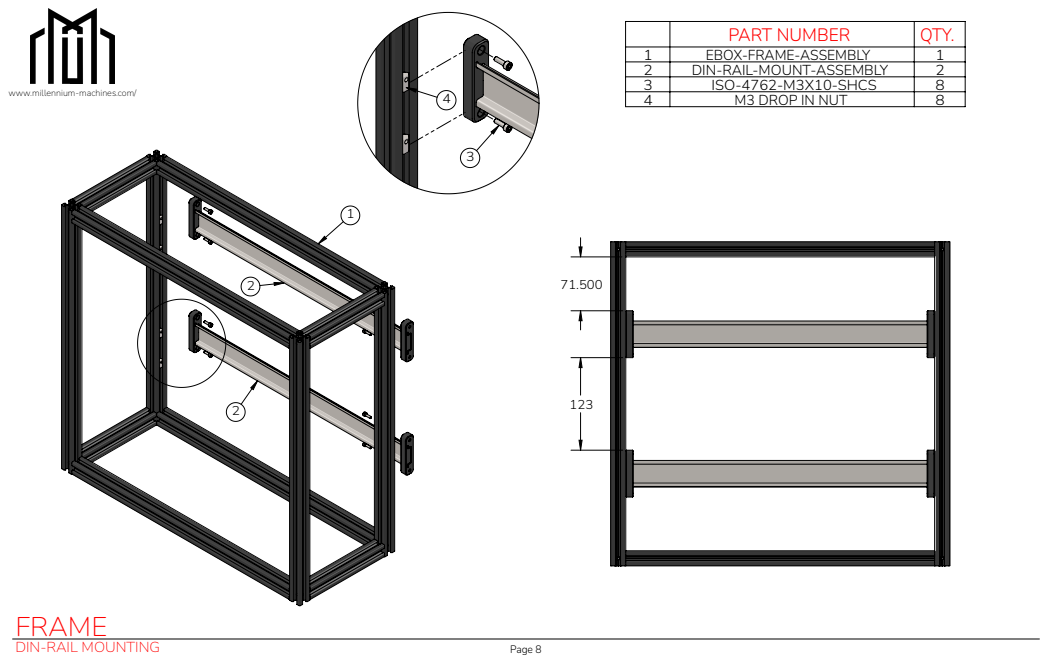
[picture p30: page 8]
DIN-RAIL MOUNTING; Page 8; FRAME

PART NUMBER | QTY.

1 | EBOX-FRAME-ASSEMBLY | 1
2 | DIN-RAIL-MOUNT-ASSEMBLY | 2
3 | ISO-4762-M3X10-SHCS | 8
4 | M3 DROP IN NUT | 8

www.millennium-machines.com/

www.millennium-machines.com/

PART NUMBER | QTY.

1 | CABLE-DUCT-165mm | 6
2 | CABLE-DUCT-145mm | 4
3 | CABLE-DUCT-T-JUNCTION | 2
4 | CABLE-DUCT-ELBOW | 4

Don’t start putting this together yet, we are going to
assemble this in the EBox Frame so that we know

our alignment is perfect.

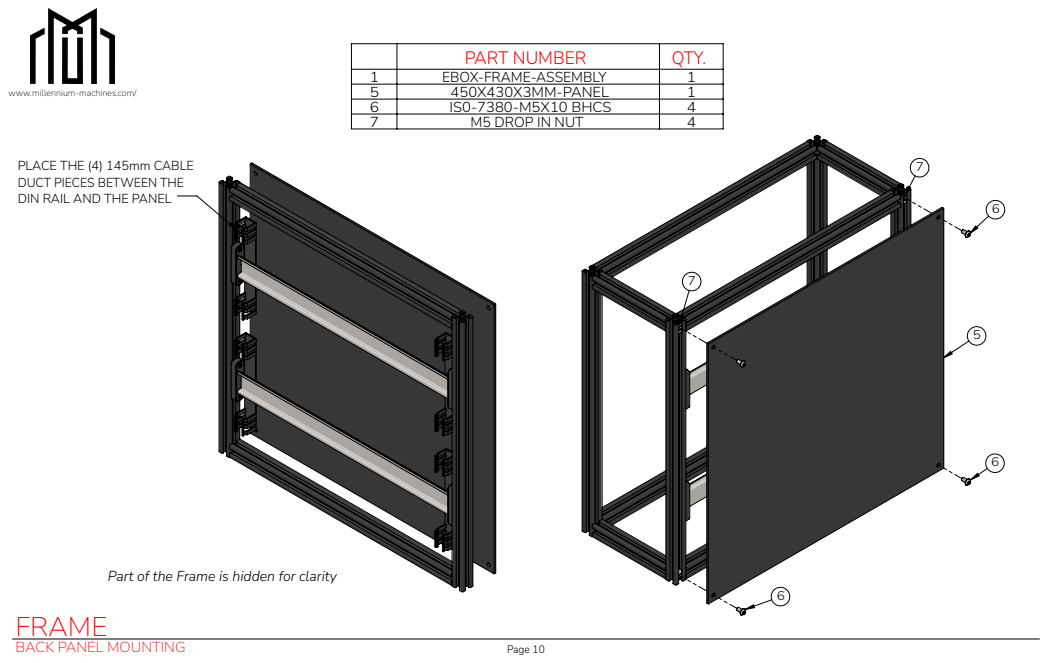
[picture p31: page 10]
BACK PANEL MOUNTING; Page 10

PART NUMBER | QTY.

1 | EBOX-FRAME-ASSEMBLY | 1
5 | 450X430X3MM-PANEL | 1
6 | IS0-7380-M5X10 BHCS | 4
7 | M5 DROP IN NUT | 4

www.millennium-machines.com/

PLACE THE (4) 145mm CABLE
DUCT PIECES BETWEEN THE
DIN RAIL AND THE PANEL

Part of the Frame is hidden for clarity
FRAME

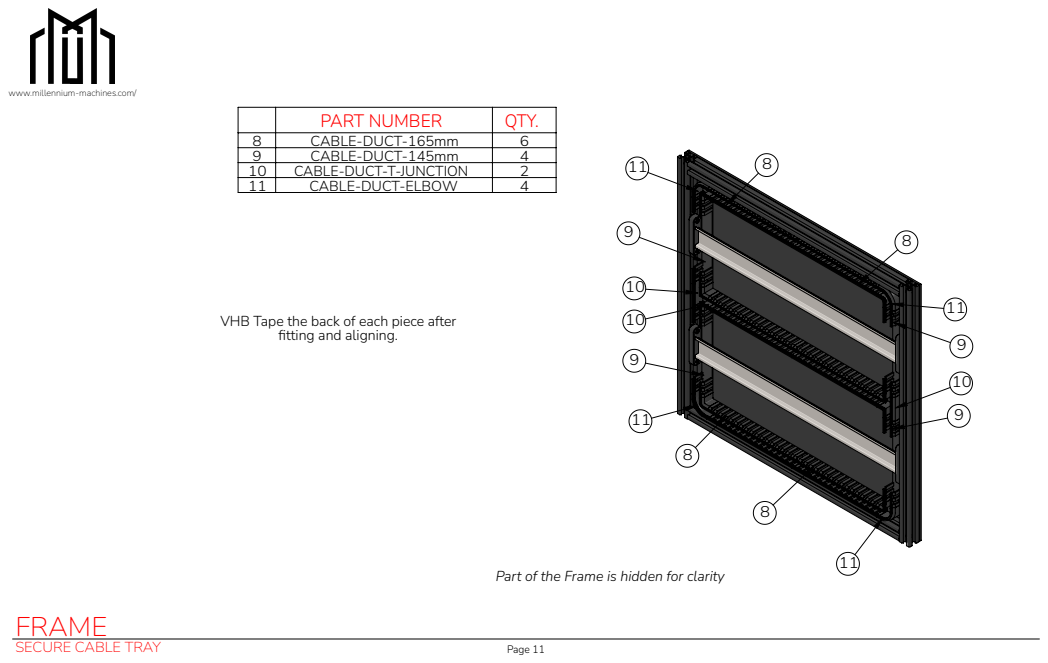
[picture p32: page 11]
SECURE CABLE TRAY; Page 11; FRAME

www.millennium-machines.com/

PART NUMBER | QTY.

8 | CABLE-DUCT-165mm | 6
9 | CABLE-DUCT-145mm | 4
10 | CABLE-DUCT-T-JUNCTION | 2
11 | CABLE-DUCT-ELBOW | 4

VHB Tape the back of each piece after

fitting and aligning.

Part of the Frame is hidden for clarity

www.millennium-machines.com/

1 | REAR-INLET-COVER | 1
2 | M3X3MM HEATSET INSERT | 4

2 | 120mm FAN | 1
3 | ISO-4762-M3X30-SHCS | 4

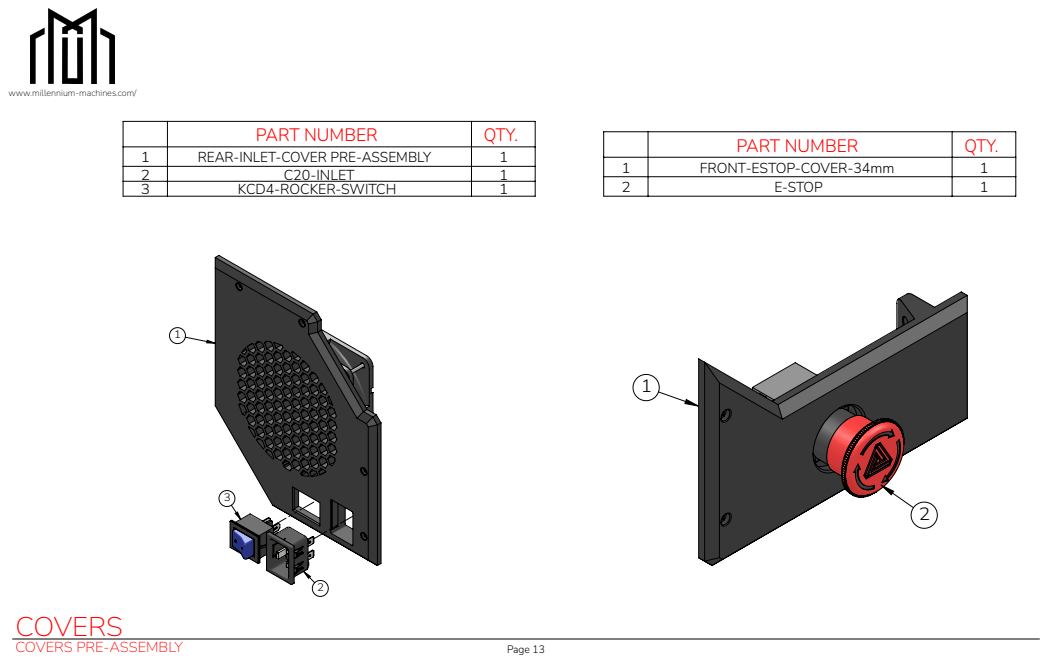
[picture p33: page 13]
COVERS PRE-ASSEMBLY; Page 13; COVERS

www.millennium-machines.com/

PART NUMBER | QTY.

1 | REAR-INLET-COVER PRE-ASSEMBLY | 1
2 | C20-INLET | 1
3 | KCD4-ROCKER-SWITCH | 1

1 | FRONT-ESTOP-COVER-34mm | 1
2 | E-STOP | 1

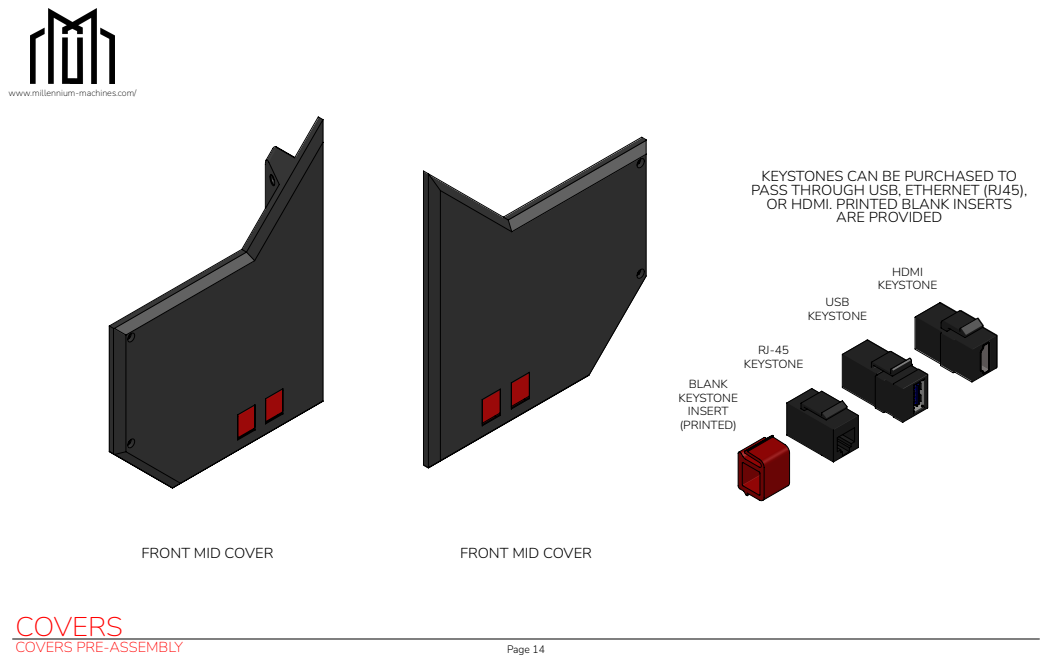
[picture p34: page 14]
COVERS PRE-ASSEMBLY; Page 14; COVERS; BLANK KEYSTONE INSERT (PRINTED); RJ-45 KEYSTONE; USB KEYSTONE; HDMI KEYSTONE; FRONT MID COVER; ARE PROVIDED

www.millennium-machines.com/

KEYSTONES CAN BE PURCHASED TO
PASS THROUGH USB, ETHERNET (RJ45),
OR HDMI. PRINTED BLANK INSERTS

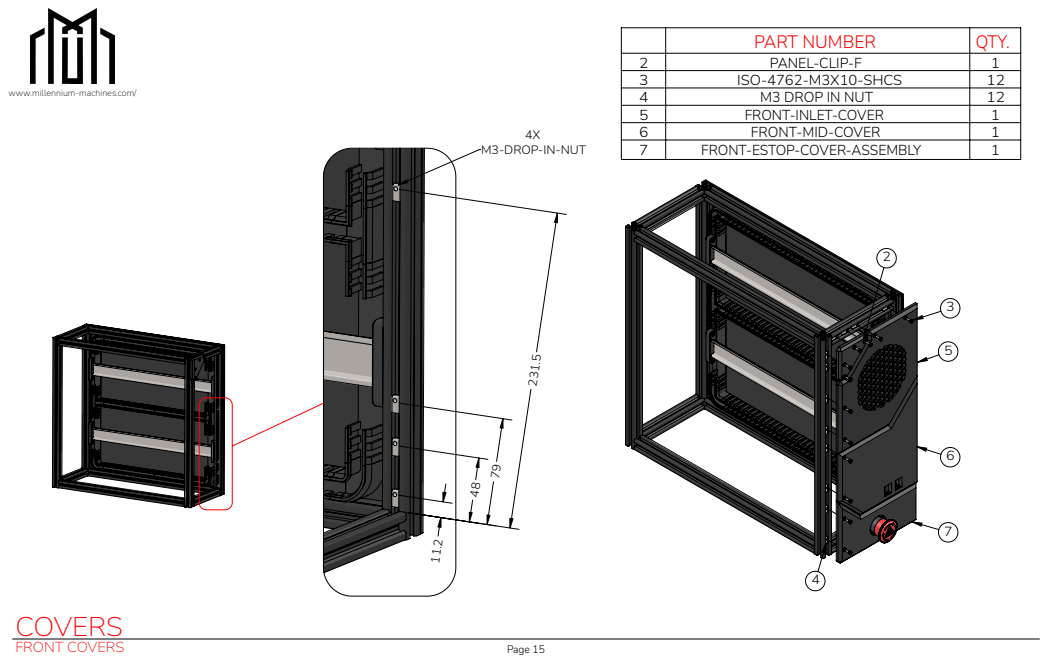
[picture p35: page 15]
FRONT COVERS; Page 15; COVERS

PART NUMBER | QTY.

2 | PANEL-CLIP-F | 1
3 | ISO-4762-M3X10-SHCS | 12
4 | M3 DROP IN NUT | 12
5 | FRONT-INLET-COVER | 1
6 | FRONT-MID-COVER | 1
7 | FRONT-ESTOP-COVER-ASSEMBLY | 1

www.millennium-machines.com/

M3-DROP-IN-NUT

www.millennium-machines.com/

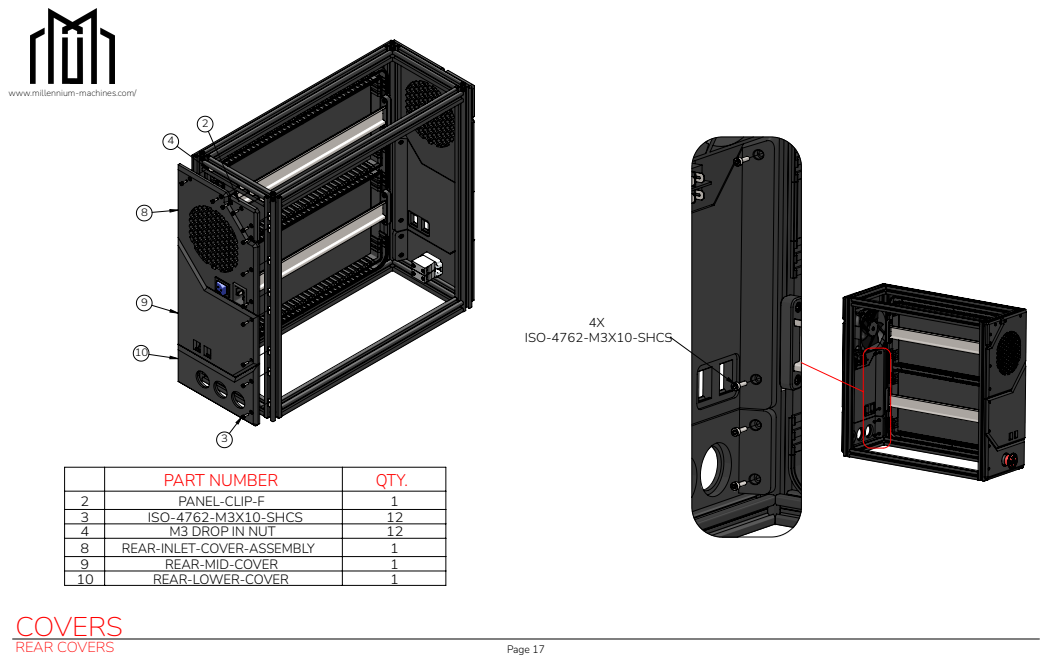
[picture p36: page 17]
REAR COVERS; Page 17; COVERS; ISO-4762-M3X10-SHCS

www.millennium-machines.com/

PART NUMBER | QTY.

2 | PANEL-CLIP-F | 1
3 | ISO-4762-M3X10-SHCS | 12
4 | M3 DROP IN NUT | 12
8 | REAR-INLET-COVER-ASSEMBLY | 1
9 | REAR-MID-COVER | 1
10 | REAR-LOWER-COVER | 1

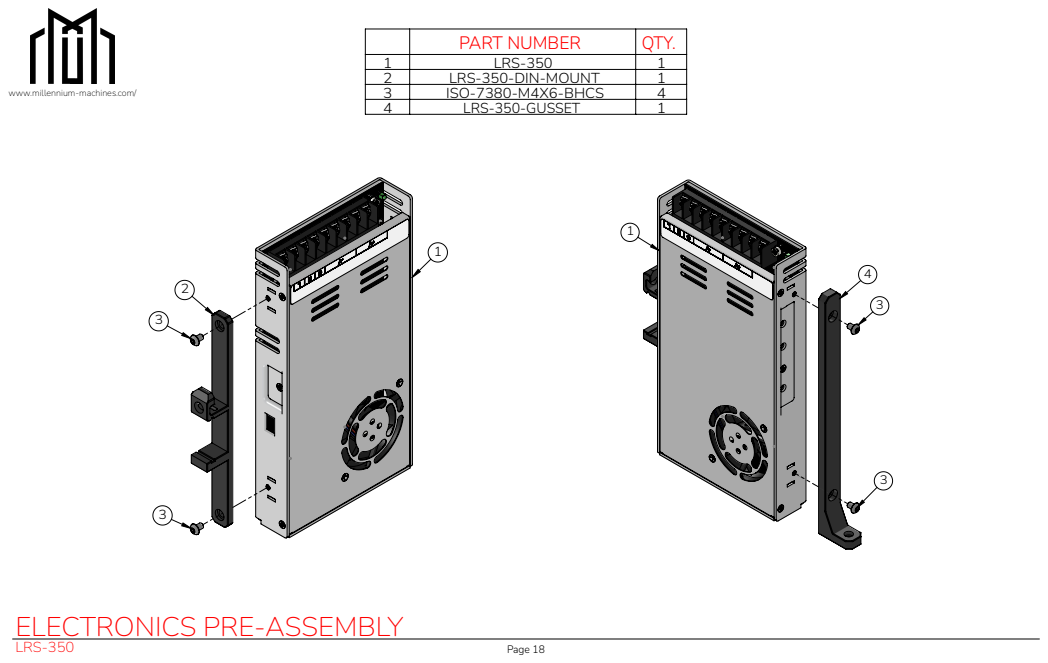
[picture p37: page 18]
LRS-350; Page 18

PART NUMBER | QTY.

1 | LRS-350 | 1
2 | LRS-350-DIN-MOUNT | 1
3 | ISO-7380-M4X6-BHCS | 4
4 | LRS-350-GUSSET | 1

www.millennium-machines.com/

ELECTRONICS PRE-ASSEMBLY

www.millennium-machines.com/

ELECTRONICS PRE-ASSEMBLY

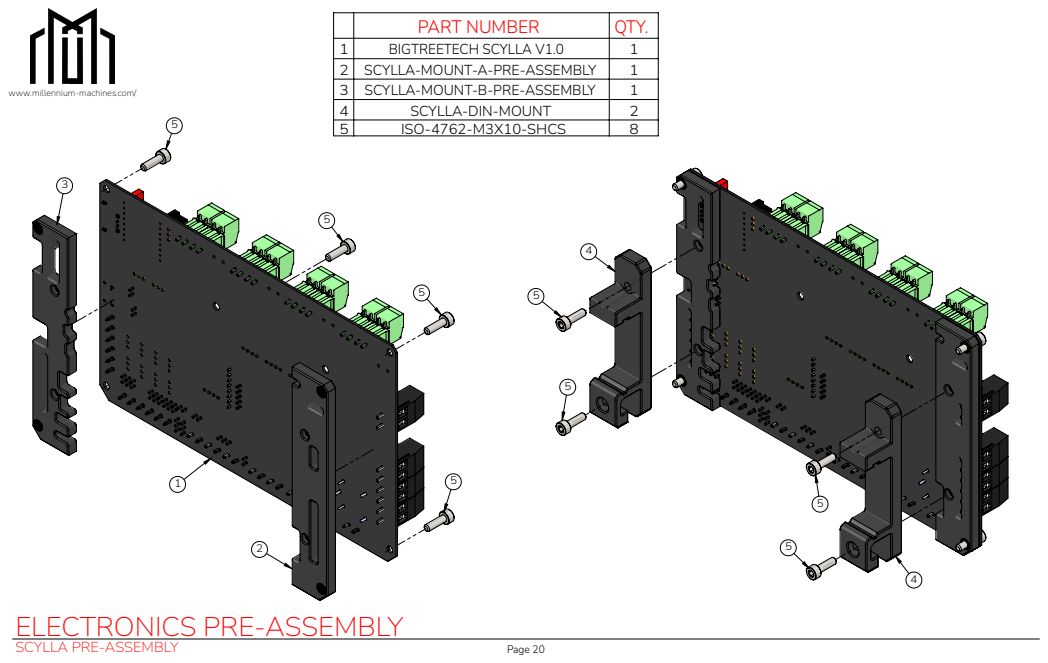
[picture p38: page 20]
SCYLLA PRE-ASSEMBLY; Page 20

PART NUMBER | QTY.

1 | BIGTREETECH SCYLLA V1.0 | 1
2 | SCYLLA-MOUNT-A-PRE-ASSEMBLY | 1
3 | SCYLLA-MOUNT-B-PRE-ASSEMBLY | 1
4 | SCYLLA-DIN-MOUNT | 2
5 | ISO-4762-M3X10-SHCS | 8

www.millennium-machines.com/

ELECTRONICS PRE-ASSEMBLY

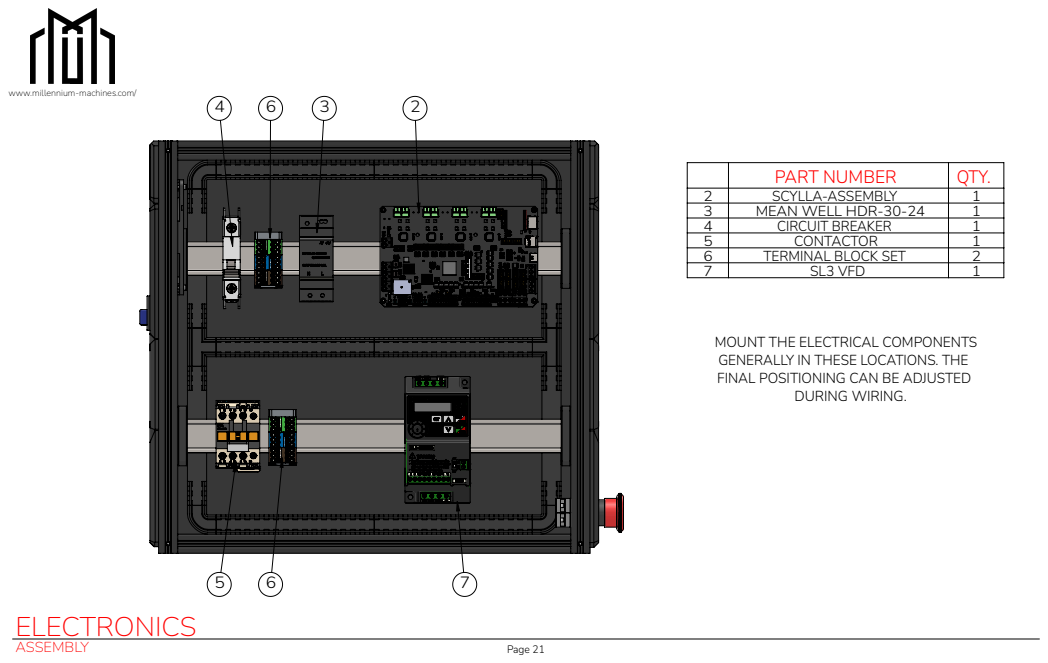
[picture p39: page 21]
ASSEMBLY; Page 21; ELECTRONICS; DURING WIRING.

www.millennium-machines.com/

PART NUMBER | QTY.

2 | SCYLLA-ASSEMBLY | 1
3 | MEAN WELL HDR-30-24 | 1
4 | CIRCUIT BREAKER | 1
5 | CONTACTOR | 1
6 | TERMINAL BLOCK SET | 2
7 | SL3 VFD | 1

MOUNT THE ELECTRICAL COMPONENTS
GENERALLY IN THESE LOCATIONS. THE
FINAL POSITIONING CAN BE ADJUSTED

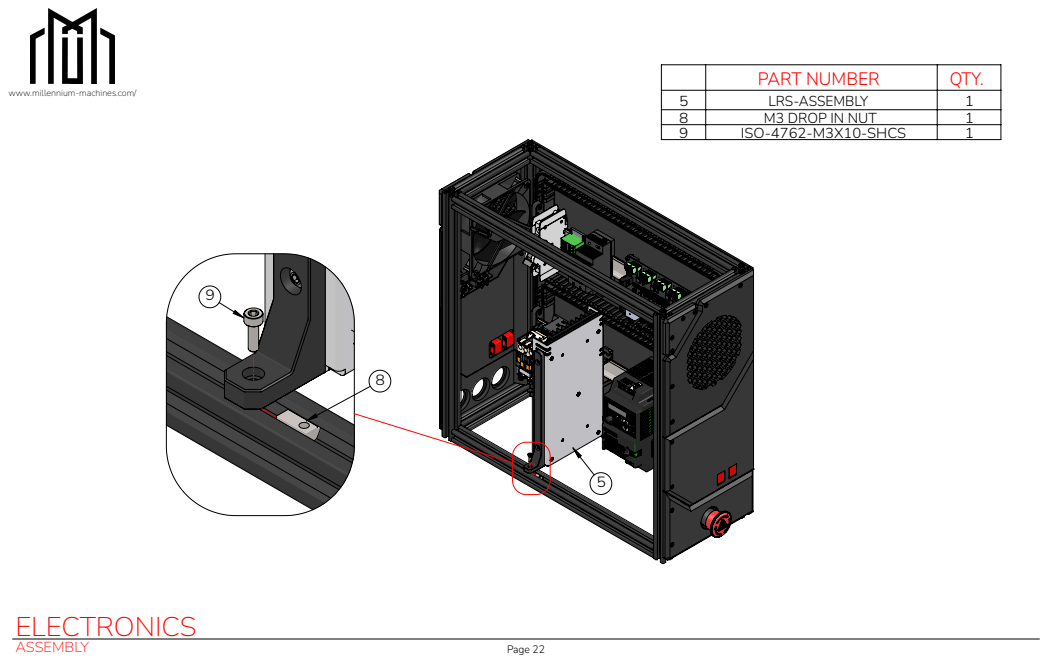
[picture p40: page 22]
ASSEMBLY; Page 22; ELECTRONICS

PART NUMBER | QTY.

www.millennium-machines.com/

5 | LRS-ASSEMBLY | 1
8 | M3 DROP IN NUT | 1
9 | ISO-4762-M3X10-SHCS | 1

www.millennium-machines.com/

MAINS INLET WIRING

IEC color scheme is shown for the mains
wiring. Depending on your region, the color
scheme and wiring standards will differ.

MINIATURE CIRCUIT BREAKER

WIRING WITH INLET & ROCKER SWITCH

TO CIRCUIT BREAKER

MAINS "UN-SAFE"
POWER DISTRIBUTION

IEC INLET W/ ROCKER SWITCH COMBO

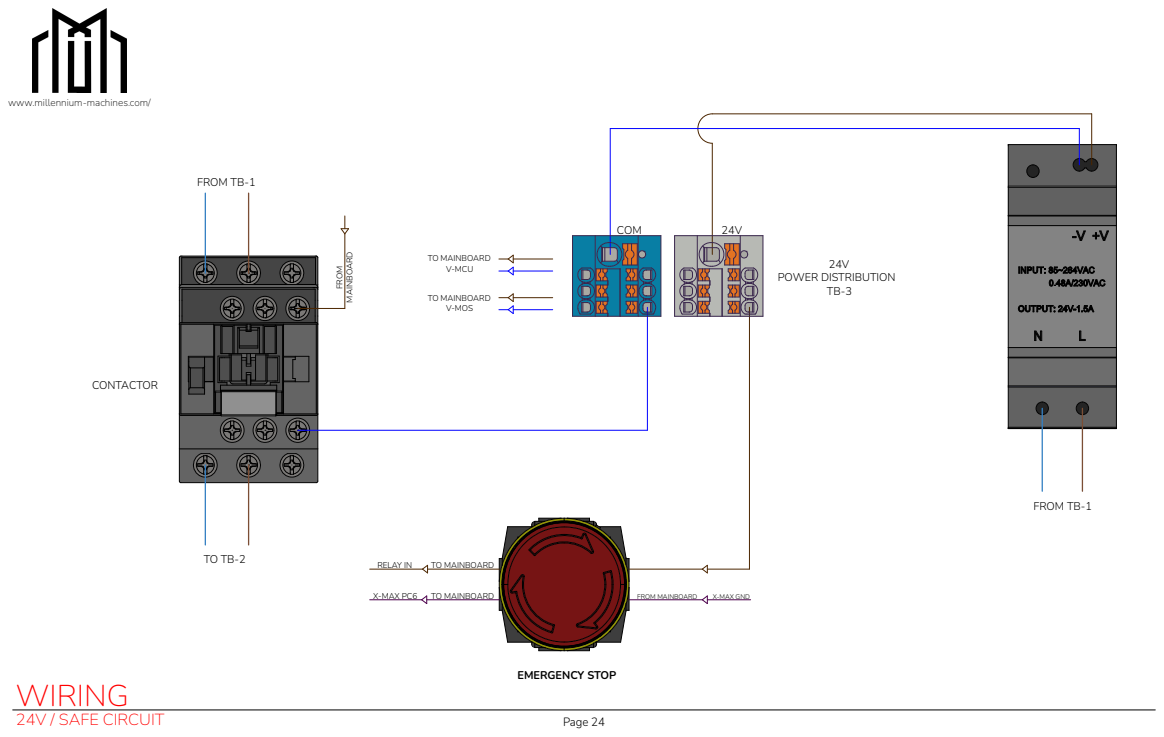
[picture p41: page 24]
24V / SAFE CIRCUIT; Page 24; WIRING; FROM TB-1; 24V POWER DISTRIBUTION TB-3; COM; FROM; MAINBOARD; TO MAINBOARD; FROM MAINBOARD; X-MAX PC6; X-MAX GND; RELAY IN; TO MAINBOARD V-MCU; TO MAINBOARD V-MOS; CONTACTOR; EMERGENCY STOP

www.millennium-machines.com/

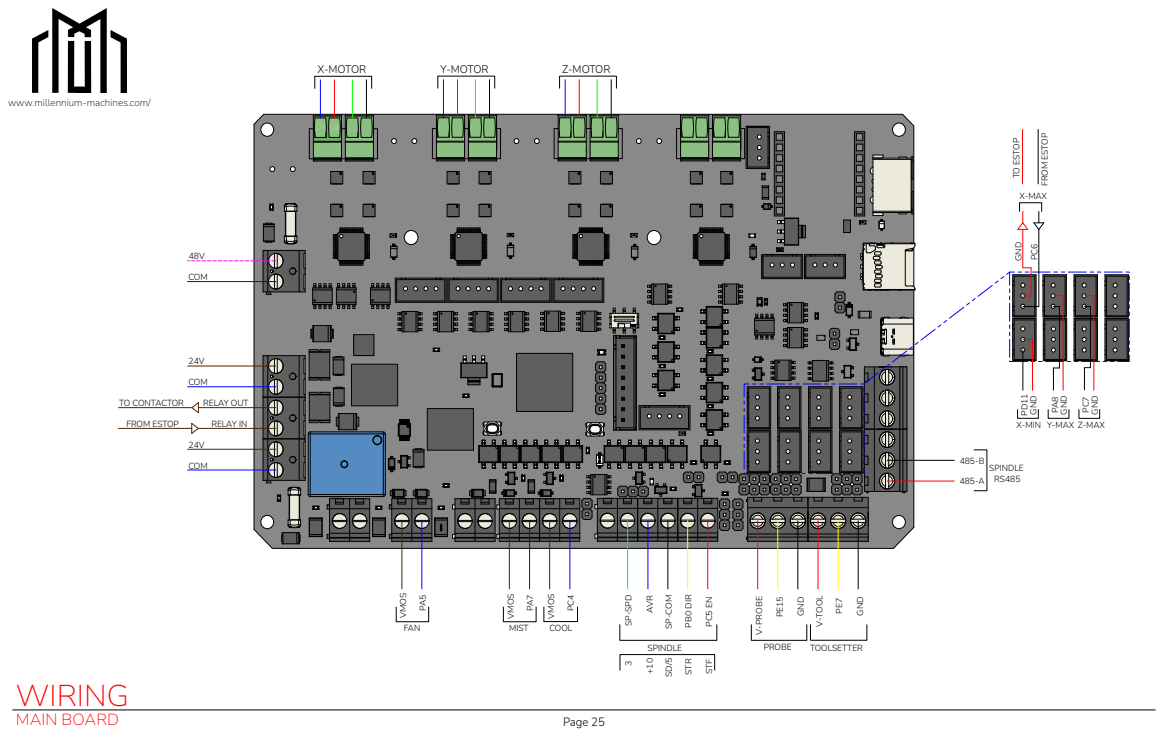
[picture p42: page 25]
MAIN BOARD; Page 25; WIRING; COM; AVR; SP-COM; PB0 DIR; SPINDLE; V-PROBE; GND; V-TOOL; PROBE; TOOLSETTER; X-MOTOR; Y-MOTOR; Z-MOTOR; SPINDLE RS485; VMOS; MIST; COOL; PD11 GND; SP-SPD; STR; STF; FROM ESTOP; TO CONTACTOR; TO ESTOP; RELAY OUT; RELAY IN; FAN

www.millennium-machines.com/

FROM ESTOP
X-MAX GND PC⁶

X-MIN Y-MAX Z-MAX

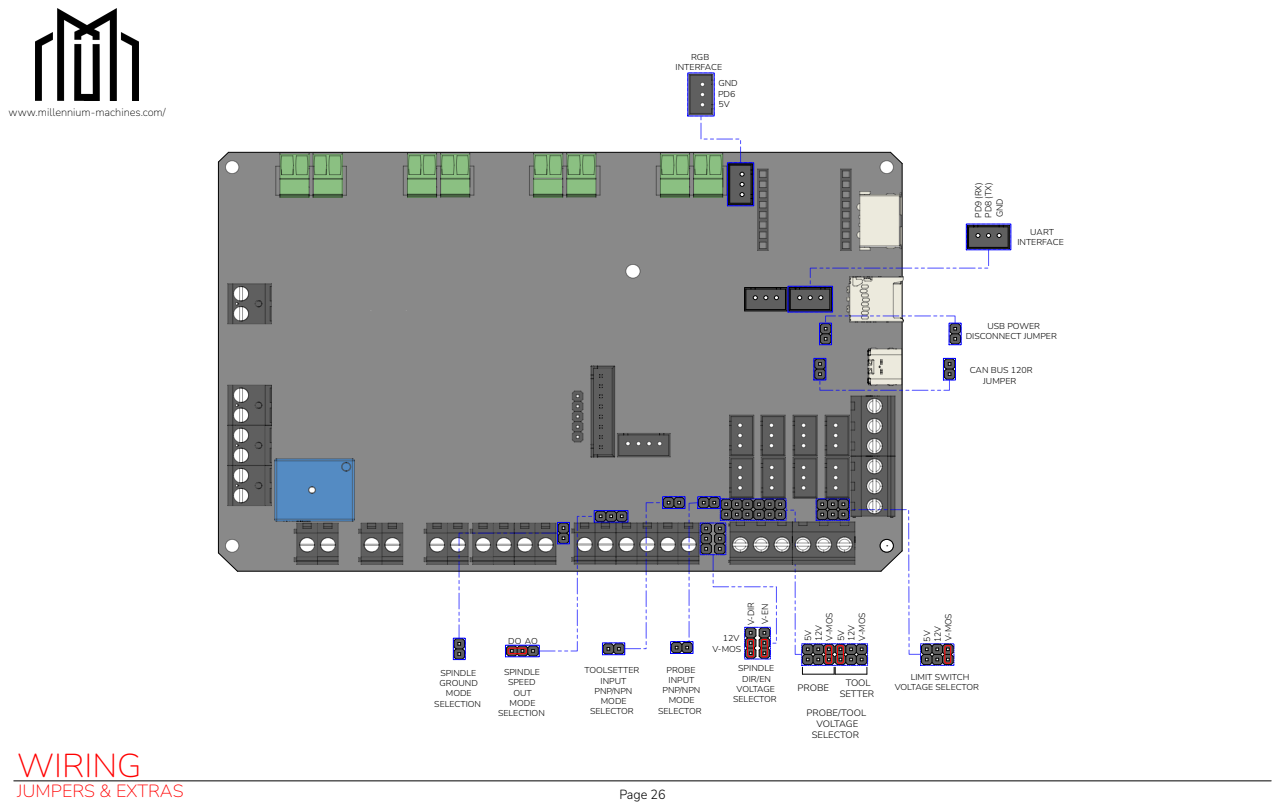
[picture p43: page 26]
JUMPERS & EXTRAS; Page 26; WIRING; V-MOS; PROBE/TOOL VOLTAGE SELECTOR; PROBE; TOOL; SETTER; SPINDLE SPEED OUT MODE SELECTION; SPINDLE GROUND MODE SELECTION; SPINDLE DIR/EN VOLTAGE; 12V V-MOS; PROBE INPUT PNP/NPN MODE SELECTOR; TOOLSETTER INPUT PNP/NPN MODE SELECTOR; LIMIT SWITCH VOLTAGE SELECTOR; RGB INTERFACE GND PD6 5V; CAN BUS 120R JUMPER; USB POWER; UART INTERFACE

www.millennium-machines.com/

DISCONNECT JUMPER PD⁹ ⁽RX⁾ PD⁸ ⁽TX⁾ GND

SELECTOR V⁻DIR V⁻EN

www.millennium-machines.com/

MAINS POWER SAFE
POWER DISTRIBUTION

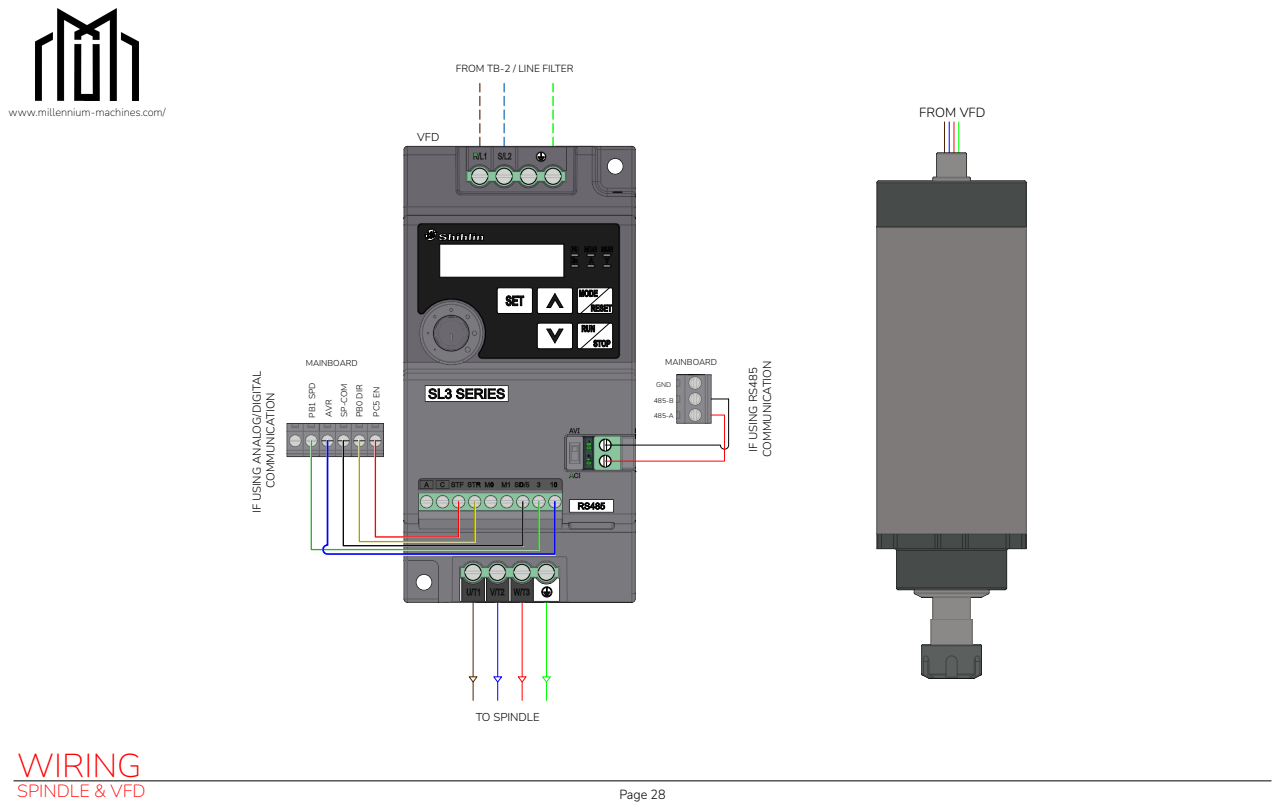
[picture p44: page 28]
SPINDLE & VFD; Page 28; WIRING; IF USING RS485; COMMUNICATION; VFD; MAINBOARD; TO SPINDLE; GND; PB1 SPD; AVR; SP-COM; PB0 DIR; FROM VFD

FROM TB-2 / LINE FILTER

www.millennium-machines.com/

IF USING ANALOG/DIGITAL

X-MOTOR | Y-MOTOR | Z-MOTOR

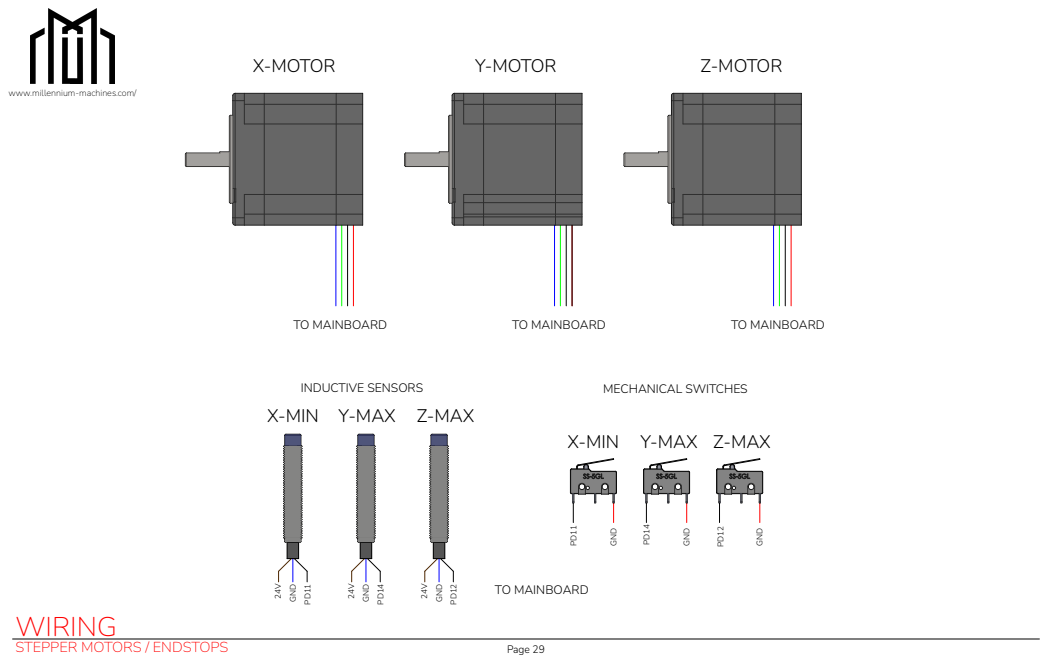
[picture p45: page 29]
STEPPER MOTORS / ENDSTOPS; Page 29; WIRING; INDUCTIVE SENSORS; MECHANICAL SWITCHES; TO MAINBOARDPD¹¹; GND; TO MAINBOARD

www.millennium-machines.com/

X-MIN Y-MAX Z-MAX GND PD¹² ²⁴V GND PD¹⁴ ²⁴V GND PD¹¹ ²⁴V

X-MIN Y-MAX Z-MAX

www.millennium-machines.com/

Depending on where you sourced your
toolsetter, it may only have 2 pins. If so, you
would connect PE15 and GND.

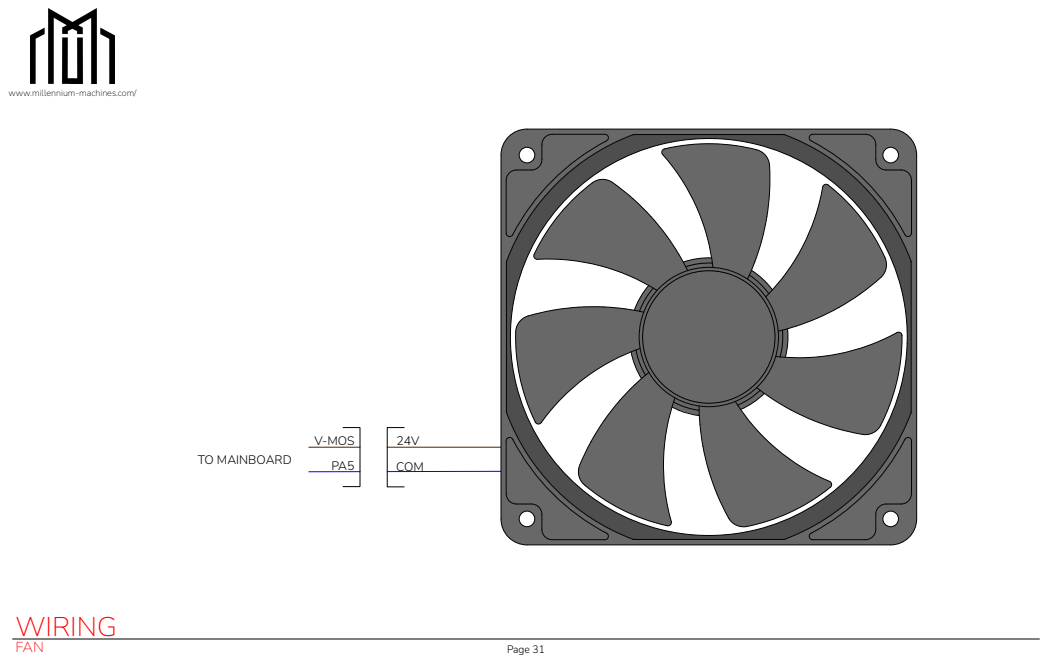
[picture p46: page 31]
FAN; Page 31; WIRING; COM; V-MOS PA5 TO MAINBOARD

www.millennium-machines.com/

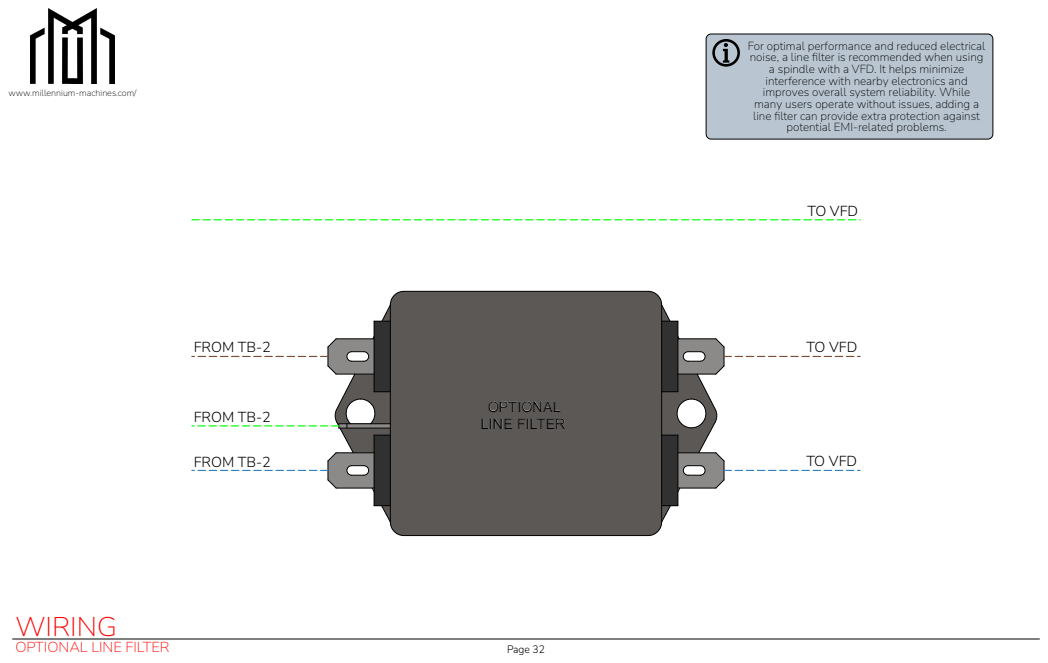
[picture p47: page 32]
OPTIONAL LINE FILTER; Page 32; WIRING; FROM TB-2; TO VFD

For optimal performance and reduced electrical
noise, a line filter is recommended when using
a spindle with a VFD. It helps minimize
interference with nearby electronics and
improves overall system reliability. While
many users operate without issues, adding a
line filter can provide extra protection against
potential EMI-related problems.

www.millennium-machines.com/

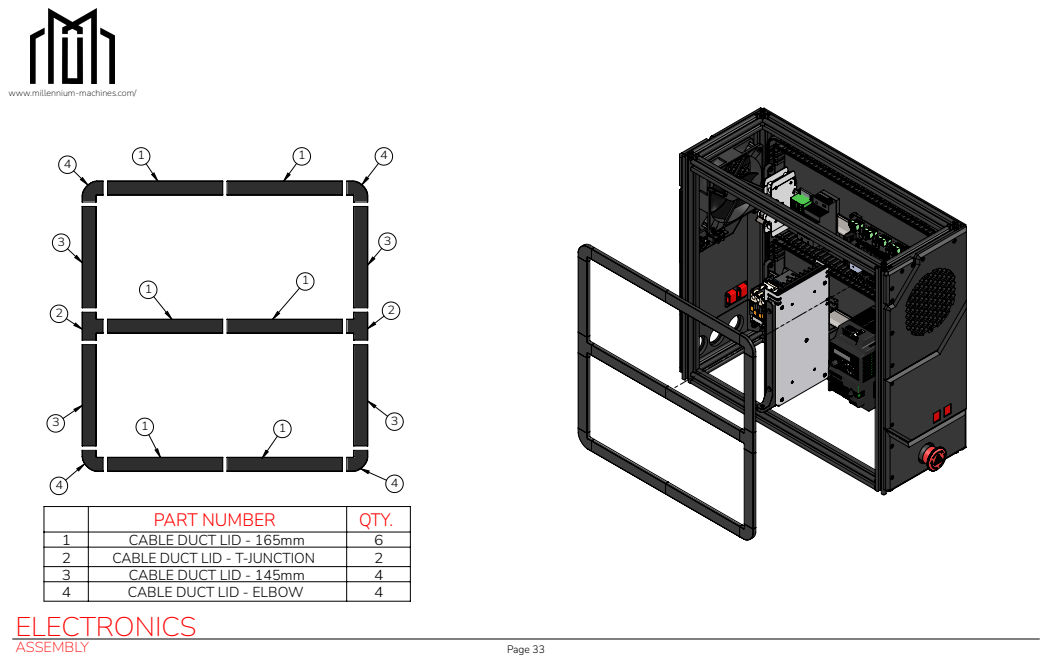
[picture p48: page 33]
ASSEMBLY; Page 33; ELECTRONICS

www.millennium-machines.com/

PART NUMBER | QTY.

1 | CABLE DUCT LID - 165mm | 6
2 | CABLE DUCT LID - T-JUNCTION | 2
3 | CABLE DUCT LID - 145mm | 4
4 | CABLE DUCT LID - ELBOW | 4

PART NUMBER | QTY.

www.millennium-machines.com/

2 | 450X186X3MM-PANEL | 1
3 | ISO-7380-M5X12 BHCS | 4
4 | EXTRUSION-HANDLE | 2

3 | PRINTED-FOOT | 4
4 | ISO-7380-M5X12 BHCS | 4

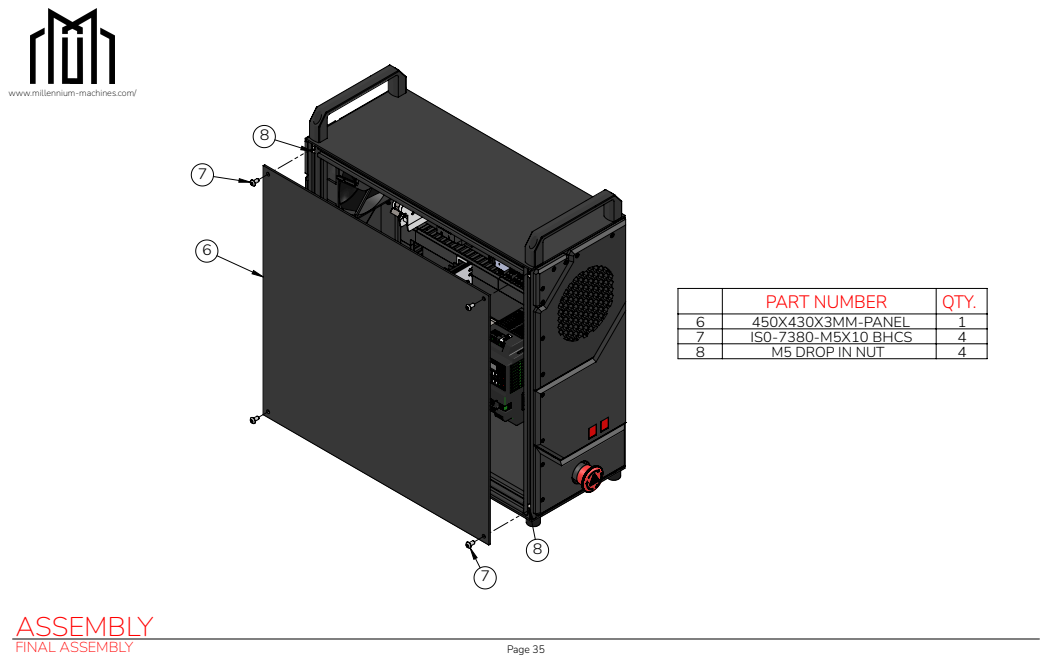
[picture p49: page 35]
FINAL ASSEMBLY; Page 35; ASSEMBLY

www.millennium-machines.com/

PART NUMBER | QTY.

6 | 450X430X3MM-PANEL | 1
7 | IS0-7380-M5X10 BHCS | 4
8 | M5 DROP IN NUT | 4

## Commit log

2026-05-16 Uploading files for the UEB
    [145mm-Lid-x4-A.stl, 145mm-Tray-x4-A.stl, 165mm-Lid-x6-A.stl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]
2026-05-18 Minor BOM fixes
    [Electronics Cabinet BOM.xlsx]
2026-06-10 Update wiring diagram to show Estop circuit using GND instead of 24V. Added the EBox assembly manual
2026-07-29 Fix of Front Mid Panel to remove screws from STL
    [Front-Mid-Cover-x1-A.stl]
2026-11-07 LDO supplied AMF350 PSU mount
2026-11-07 Updated print list to list LDO PSU mount
